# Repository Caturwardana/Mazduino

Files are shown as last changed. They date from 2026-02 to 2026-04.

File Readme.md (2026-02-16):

# Mazduino
*Mazduino ECU* is compatible with firmware from rusEFI and can also be used with Speeduino.  
For tuning and configuration, you can use the Tuner Studio software.

## Mazduino ECU Compact
Assembled Mazduino ECU
A compact and customizable Engine Control Unit (ECU) designed for **4-cylinder engines with full sequential injection and ignition**.

## Mazduino ECU Mini 6Ch
Assembled Mazduino ECU
A mini 6-channel version of the Mazduino ECU for **6-cylinder engines with full sequential injection and ignition**.

## Mazduino ECU Lite Edition
Mazduino Lite Edition
A lightweight and compact ECU designed for **4-cylinder engines with full sequential injection and wasted spark ignition**.

## Mazduino Display
Mazduino Display
A dedicated dashboard ECU display module that shows real-time vehicle data retrieved from the main ECU.

## Mazduino WBO (Wideband Oxygen Sensor Controller)
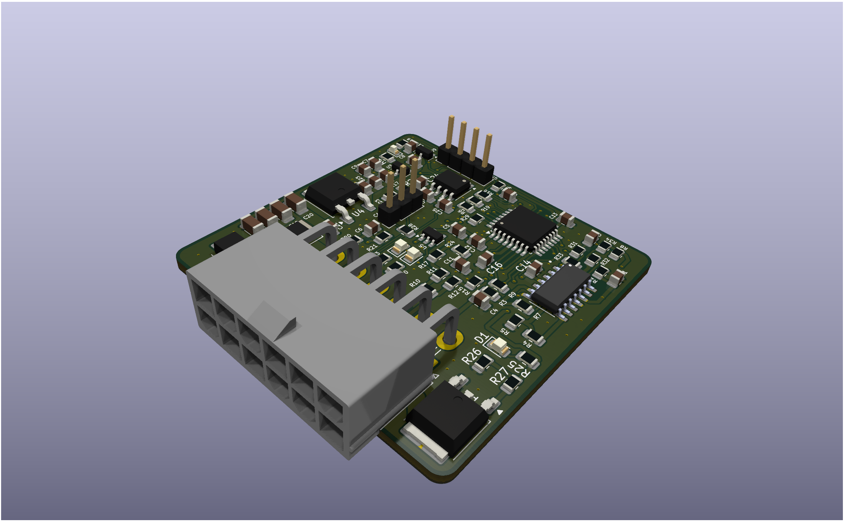
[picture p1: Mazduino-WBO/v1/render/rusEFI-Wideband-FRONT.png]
Mazduino WBO

A wideband oxygen sensor controller that communicates with the ECU via CAN bus for accurate air-fuel ratio monitoring. Supports LSU 4.2, LSU 4.9, and LSU 4.9 Adv sensors with easy manual assembly design.

*Documentation for all variants will be updated as soon as possible.*

## Links
### Mazduino
- **Official Website**: https://www.mazduino.com
- **Documentation & WIKI**: https://wiki.mazduino.com

### Firmware & Software
- **rusEFI**: https://rusefi.com/
- **Speeduino**: https://speeduino.com/home/
- **Tuner Studio**: https://www.tunerstudio.com/index.php/tuner-studio

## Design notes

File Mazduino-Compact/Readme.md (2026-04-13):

# Mazduino Compact
Assembled Mazduino ECU

Mazduino Compact is compatible with firmware from rusEFI and can also be used with Speeduino.  
For tuning and configuration, you can use the Tuner Studio software.

## Downloads

### Latest Version (v2.5)
- [Download Schematic (PDF)](https://github.com/amrikarisma/Mazduino/blob/main/Mazduino-Compact/v2.5/Schematics.pdf)
- [Interactive BOM v2.5](https://www.mazduino.com/ibom/compact-2-5-ibom.html)

### Other Versions
- [Download Schematic v2.4 (PDF)](https://github.com/amrikarisma/Mazduino/blob/main/Mazduino-Compact/v2.4/Schematics.pdf)
- [Interactive BOM v2.4](https://www.mazduino.com/ibom/compact-2-4-ibom.html)
- [Interactive BOM v2.3](https://www.mazduino.com/ibom/compact-2-3-ibom.html)
- [Interactive BOM v2.2](https://www.mazduino.com/ibom/compact-2-2-ibom.html)
- [Interactive BOM v2.0](https://www.mazduino.com/ibom/compact-2-0-ibom.html)
- [Interactive BOM v1.3](https://www.mazduino.com/ibom/compact-1-3-ibom.html)
*Interactive BOM for other versions will be available soon*

## Changelog

### v1.0
- Initial testing

### v1.1
- Fixed USB-C to USB-C connection: rerouted 5.1k resistor to CC1 & CC2  
- Corrected silkscreen typo  

### v1.2
- Added low-current output for main relay  
- Added spare analog input  
- Added jumper footprint  

### v2.0
- Replaced connector with a 33-pin Yamaha automotive connector  
- Changed 12V capacitor size from 5x5 to 6x5  

### v2.1
- Added one high-current low-side MOSFET for boost/VVT/Idle2 control  
- Added direct knock sensor support using an op-amp IC  
- Supported two types of CAN bus transceivers: MCP2551 or TJA1051T/3  
- Added a dedicated connector for CAN bus communication  
- Added a pin header footprint for VBAT, allowing real-time clock backup with a 3.3V battery

### v2.2
- Added high-side MOSFET for 12V switching control (alternator and other components requiring 12V switching)  

### v2.3
- Fixed MCU mapping for 12V battery input and knock sensor input  
- Optimized component selection and PCB layout for improved reliability and manufacturing efficiency  
- Added JST connector footprint for usb connector options  
- Added CR1220 battery holder footprint for real-time clock backup power  

### v2.4
- Optimized Hall input circuit  
- Updated pin mapping for knock input and TPS input  

### v2.5
- Optimized Hall input and analog input  
- Updated pin mapping for high-side outputs  
- HS1 moved to PD15 and HS2 moved to PD14  
- Added optional jumper for HS2 (High Side Output 2)

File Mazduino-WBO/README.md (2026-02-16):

# Mazduino WBO (Wideband Oxygen Sensor Controller)

## PCB Views

| Top View (Component Side) | Bottom View |
|:---:|:---:|
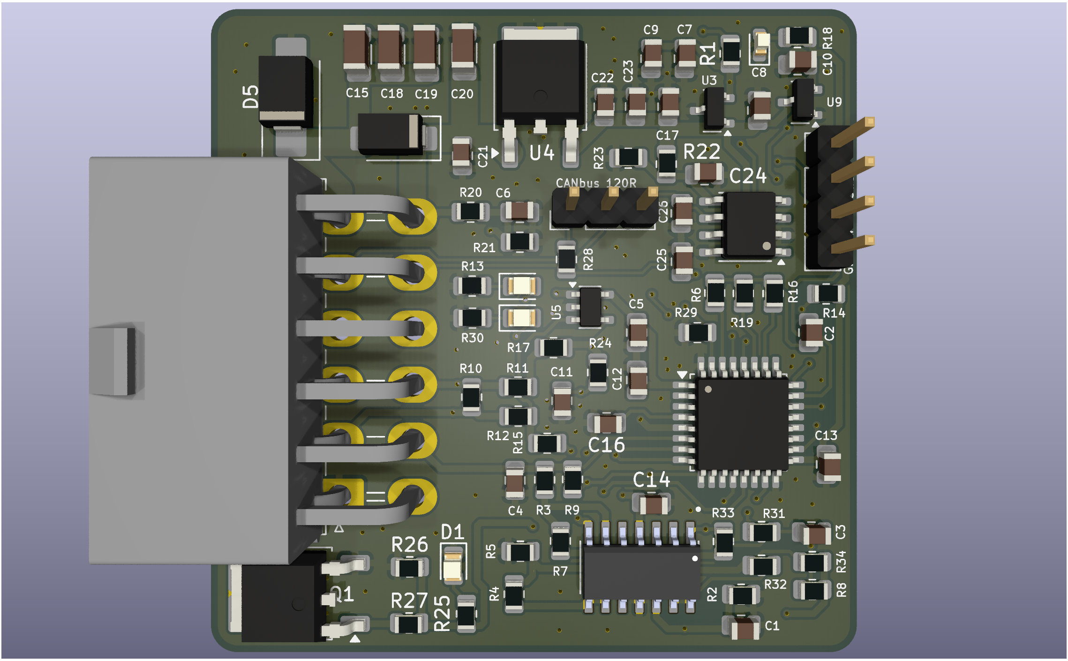
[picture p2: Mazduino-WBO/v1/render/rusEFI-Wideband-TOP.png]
Mazduino WBO Top
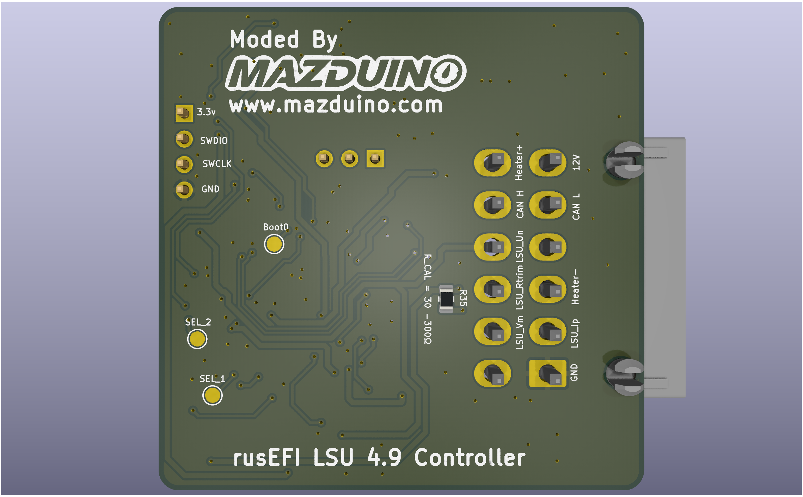
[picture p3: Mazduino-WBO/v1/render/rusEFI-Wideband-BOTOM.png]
Mazduino WBO Bottom
|  |  |

The **Mazduino WBO** is a Fork of the original Wideband Oxygen sensor controller designed to work with the rusEFI ecosystem. This project is specifically redesigned with components that are easier to manually assemble and uses economical Molex connectors to reduce cost while maintaining functionality.

## Overview

The Mazduino WBO provides accurate air-fuel ratio (AFR) monitoring for engine tuning and performance optimization. This module communicates with your ECU via **CAN bus**, enabling real-time AFR data transmission for precise fuel management. It's designed to be a cost-effective solution for DIY engine management enthusiasts who want reliable wideband oxygen sensor control.

## Key Features

- **CAN Bus Communication**: Communicates with ECU via CAN bus for real-time AFR data transmission
- **Multiple LSU Sensor Support**: Compatible with LSU 4.2, LSU 4.9, and LSU 4.9 Adv sensors
- **Easy Manual Assembly**: Redesigned with components that are straightforward to solder and assemble by hand
- **Economical Connectors**: Uses cost-effective Molex connectors instead of expensive alternatives
- **rusEFI Compatible**: Fully compatible with the rusEFI ecosystem for seamless integration
- **Open Source**: Complete schematics, PCB design files, and firmware available
- **Proven Design**: Based on the reliable [mck1117/wideband](https://github.com/mck1117/wideband) controller

## Hardware Versions

### v1.0
- Initial release with improved component selection for manual assembly
- Cost-optimized Molex connector implementation
- Supports LSU 4.2, LSU 4.9, and LSU 4.9 Adv sensors (tested and verified with LSU 4.9)
- Complete gerber files and assembly documentation included
- **Interactive BOM**: [View Interactive Bill of Materials](https://www.mazduino.com/ibom/wideband-controller-v1-ibom.html)

## Firmware

This project uses the **rusEFI WBO F0** firmware, which provides:
- Accurate AFR readings
- CAN bus communication
- Calibration and diagnostic features

**Firmware Source**: [rusEFI WBO F0 Implementation](https://github.com/rusefi/rusefi/pull/8870)

## Getting Started

### Hardware Requirements
- Mazduino WBO PCB (v1.0 or later)
- **Wideband oxygen sensor**: Supports LSU 4.2, LSU 4.9, and LSU 4.9 Adv (tested with LSU 4.9)
- 12V power supply
- **CAN bus connection** to ECU (primary communication method)

### Connector Pinout

The Mazduino WBO uses a **Molex 2x6 connector** for easy assembly and cost-effective connections.

Mazduino WBO Front

#### Pinout Layout:

<table>
<tr>
<td>Heater+</td>
<td>CANH</td>
<td>LSU_Un</td>
<td>LSU_Rtrim</td>
<td>LSU_Vm</td>
<td>Empty</td>
</tr>
<tr>
<td>+12V</td>
<td>CANL</td>
<td>Empty</td>
<td>Heater-</td>
<td>LSU_Ip</td>
<td>GND</td>
</tr>
</table>

*Row 1 (Top) and Row 2 (Bottom) of the Molex 2x6 connector*

#### LSU 4.9 Wire Colors:
| Signal | Wire Color | Pin Location |
|:---|:---|:---|
| LSU_Ip | Red | Row 2, Pin 5 |
| Heater- | White | Row 2, Pin 4 |
| Heater+ | Grey | Row 1, Pin 1 |
| LSU_Vm | Yellow | Row 1, Pin 5 |
| LSU_Rtrim  | Green | Row 1, Pin 4 |
| LSU_Un | Black | Row 1, Pin 3 |

### Assembly
1. Follow the assembly guide in the `v1/` directory
2. Refer to the BOM (Bill of Materials) for required components
3. Use the **[Interactive BOM](https://www.mazduino.com/ibom/wideband-controller-v1-ibom.html)** for easy component identification and placement
4. Use the provided schematics for proper component placement

### Firmware Installation
1. Download the rusEFI WBO F0 firmware from the official repository
2. Flash the firmware using your preferred STM32 programming tool
3. Configure the controller according to your sensor specifications

## Project Structure

```
Mazduino-WBO/
├── README.md           # This file
└── v1/                 # Version 1.0 files
    ├── Readme.md       # Version-specific documentation
    ├── Schematics.pdf  # Circuit schematics
    └── gerber/         # PCB manufacturing files
        ├── bom.csv             # Bill of materials
        ├── designators.csv     # Component designators
        ├── netlist.ipc         # Net list file
        ├── positions.csv       # Component positions
        └── rusEFI-WBO.zip     # Complete gerber package
```

## Attribution

This project is a fork of the excellent work by [mck1117](https://github.com/mck1117) on the original [wideband controller](https://github.com/mck1117/wideband). The Mazduino variant focuses on improving manufacturability and reducing cost while maintaining the proven functionality of the original design.

## Related Projects

- **Original Wideband Controller**: https://github.com/mck1117/wideband
- **rusEFI Project**: https://github.com/rusefi/rusefi
- **Mazduino ECU Family**: See main project directory for other Mazduino variants

## Contributing

Contributions are welcome! Please feel free to submit issues, feature requests, or pull requests to improve the Mazduino WBO design.

## License

This project follows the same license terms as the original wideband controller project.

## Support & Documentation

- **Official Website**: https://www.mazduino.com
- **Documentation & WIKI**: https://wiki.mazduino.com
- **rusEFI Community**: https://rusefi.com/forum/

---

*For questions or support, please visit the Mazduino community forums or create an issue in this repository.*

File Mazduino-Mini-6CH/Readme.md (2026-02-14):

# Mazduino Mini 6Ch

Mazduino Mini 6Ch is compatible with firmware from rusEFI and can also be used with Speeduino.  
For tuning and configuration, you can use the Tuner Studio software.

## Preview
<table>
  <tr>
    <td>3D Render top</td>
    <td>3D Render bottom</td>
  </tr>
  <tr>
    <td>3D Render side</td>
    <td>Assembled Mazduino ECU</td>
  </tr>
</table>

## Features
- Processor/MCU: STM32F407
- 6 Channel Coil outputs for Smart Coil (For dumb coil, please add external IGBT)
- 6 Channel Injector outputs
- 2 High Current Outputs (Idle/Boost/VVT)
- Tachometer Output
- Fuel Pump Low Current Output
- FAN Low Current Output
- AC Compressor Low Current Output
- CKP Trigger Input (Hall/Optical/VR)
- CMP Trigger Input (Hall/Optical/VR)
- Supports VR-Conditioner Module (DIP 8)
- Supports Stepper Module (DRV8825)
- External MAP Sensor Analog Input
- TPS Sensor Analog Input
- IAT Sensor Analog Input
- ECT/CLT Sensor Analog Input
- O2 Sensor Analog Input
- Spare Analog Input 1 (Can be used for Fuel Pressure Sensor or others)
- Spare Analog Input 2 (Can be used for Oil Pressure Sensor or others)
- AC Switch Digital Input/GND signal
- Launch Control Input
- Clutch Input
- VSS Input
- Supports Micro SD Card for data logging via SPI
- Supports CANbus communication with MCP2551 IC
- Automotive 48-pin Yamaha ECU Connector

## Downloads

### Latest Version (v1.4)
- [Download Schematic (PDF)](https://github.com/amrikarisma/Mazduino/blob/main/Mazduino-Mini-6CH/v1.4/Schematics.pdf)
- [Interactive BOM v1.4](https://www.mazduino.com/ibom/mini6ch-1-4-ibom.html)

### Other Versions
- [Interactive BOM v1.3](https://www.mazduino.com/ibom/mini6ch-1-3-ibom.html)
- [Interactive BOM v1.3B](https://www.mazduino.com/ibom/mini6ch-1-3b-ibom.html)
- [Interactive BOM v1.2](https://www.mazduino.com/ibom/mini6ch-1-2-ibom.html)
  
## Changelog

### v1.0
- Initial Release

### v1.1
- Fix USB D+ and D-
- Add 2 Spare analog inputs
- Change AC Switch from Analog Input to Digital Pin (GND signal)

### v1.2
- Replace footprint Capacitor for Input Regulator 5V from 5x5 to 8x6
- Add low current output for Main relay control
- Fix DRV8825 schema for rusEFI

### v1.3
- Added ETB support
- Added Knock sensor support

### v1.3B
- Added 1 spare input to support ETB. For ETB to work, it needs TPS1, TPS2, PPS1, PPS2. Previously PPS2 shared with O2/IAT input (unused analog input)
- CAN IC only supports TJA1051T/J/3 (Solder jumper for MCP2551 removed)
- Footprint optimization
- DRV8825 module support is still maintained

### v1.4 (latest)
- Added spare inputs to support TPS1, TPS2, PPS1, PPS2
- Added support for ETB1 and ETB2
- Motor driver uses 2x TLE9201SG ICs (can be used for Idle Stepper Motor when not used for ETB)
- Removed DRV8825 module support

---

*This documentation will be updated as soon as possible... please wait.*

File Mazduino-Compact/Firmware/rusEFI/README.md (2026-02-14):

# rusEFI Firmware for Mazduino-Compact

## Overview
This directory contains rusEFI firmware and configuration files for the Mazduino-Compact ECU board.

## Firmware Download Options

### Important Note
You are **not required** to use the `rusefi.hex` file that may be present in this folder. You can download the latest firmware directly from the official rusEFI build server.

### Official Download Links

#### Discovery F407 Platform
- **Download URL:** https://rusefi.com/build_server/rusefi_bundle_f407-discovery.zip
- **Platform:** Discovery F407
- **Description:** Latest stable firmware build for STM32F407-based boards

#### Mega100 Platform  
- **Download URL:** https://rusefi.com/build_server/rusefi_bundle_mega100.zip
- **Platform:** Mega100
- **Description:** Latest stable firmware build for Mega100 platform

## Installation Instructions

1. Download the appropriate firmware bundle from one of the links above
2. Extract the downloaded zip file
3. Use the rusEFI Console or your preferred flashing tool to upload the firmware
4. Apply the base tune configuration from the `basetune/` folder if available

## Configuration Files

Check the `basetune/` directory for:
- Base tune files (.msq)
- Configuration templates
- Sensor calibration data

## Support and Documentation

- **Official Website:** https://rusefi.com/
- **Documentation:** https://wiki.rusefi.com/
- **Community Forum:** https://rusefi.com/forum/
- **GitHub Repository:** https://github.com/rusefi/rusefi

## Compatibility

This firmware is designed for use with the Mazduino-Compact ECU board. Ensure you select the correct platform variant when downloading from the build server.

## Updates

Always check the official rusEFI build server for the latest firmware versions, as they include the newest features, bug fixes, and improvements.

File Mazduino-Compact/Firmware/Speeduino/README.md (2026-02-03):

# Speeduino Firmware for Mazduino-Compact

## Important Notice

### Custom Firmware Required
The Mazduino ECU can **ONLY** run **custom Speeduino firmware**. The official Speeduino firmware from the main project **will NOT work** with Mazduino boards due to hardware differences and pin mapping requirements.

### Compatibility Warning
- ⚠️ **DO NOT** use official Speeduino firmware releases
- ⚠️ **DO NOT** download firmware from speeduino.com for direct use
- ✅ **ONLY** use the custom firmware provided in this repository

## Board Compatibility

### Tested Hardware
- **Mazduino Compact v1.x** - ✅ Fully tested and supported

### Untested/Unsupported
- **Mazduino Compact v2.x and above** - ⚠️ Not tested with this firmware
- **Other Mazduino variants** - ⚠️ May require different firmware versions

## Firmware Versions Available

Check the version folders for available firmware builds:
- `202501/` - January 2025 custom build
- `202501.2/` - January 2025 revised build
- `basetune/` - Base configuration files

## Installation Instructions

1. **Select the appropriate version** from the available folders
2. **Use Arduino IDE or PlatformIO** to flash the custom firmware
3. **Apply base tune settings** from the `basetune/` folder
4. **Verify pin mapping** matches your specific Mazduino Compact v1 board

## Why Custom Firmware?

The Mazduino boards use different:
- Pin assignments compared to standard Arduino Mega
- Hardware layout and connections
- Sensor input configurations
- Output driver arrangements

These differences require custom firmware modifications that are not present in the official Speeduino releases.

## Support and Resources

- **Mazduino Documentation:** Check the main repository wiki
- **Speeduino Community:** https://speeduino.com/forum/ (for general Speeduino questions)
- **Custom Firmware Issues:** Report in the Mazduino project repository

## Upgrading Board Versions

If you have a **Mazduino Compact v2.x or newer**, check the appropriate firmware directory for your board version, as this firmware is specifically for v1.x boards only.

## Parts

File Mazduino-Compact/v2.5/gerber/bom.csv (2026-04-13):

Designator | Footprint | Quantity | Value | LCSC Part #
BT1 | CR1220-2 | 1 | Battery_Cell
C1, C15, C66, C67 | 0603 | 4 | 1nF | C1588
C12, C16, C19, C20, C3, C35, C38, C39, C4, C40, C41, C5, C6, C7, C8, C9 | 0603 | 16 | 100nF | C14663
C17 | CP_Elec_6.3x5.4 | 1 | 10uF
C18, C2, C24, C30, C36, C42, C43, C44, C45, C46, C54, C56 | 0603 | 12 | 100nF
C21 | CP_Elec_5x5.3 | 1 | 47uF
C22, C55 | 0603 | 2 | 1uF | C15849
C23, C26 | 0603 | 2 | 33pF | C1663
C25, C29, C31, C33, C57 | 0603 | 5 | 1uF
C27 | 0603 | 1 | 20pF | C1648
C28 | 0603 | 1 | 20pF
C32 | 0603 | 1 | 2.2uF | C23630
C34 | 0603 | 1 | 2.2uF
C37 | CP_Elec_5x5.4 | 1 | 47uF
C49 | 0603 | 1 | 3.3nF
C50 | 0603 | 1 | 680pF
C51 | 0603 | 1 | 330pF
C52 | 0603 | 1 | 47pF
C53 | 0603 | 1 | 10nF
C58, C59 | 0603 | 2 | 10nF | C57112
D1, D2, D3, D4, D7, D8, D9 | 0603 | 7 | LED
D10 | 0603 | 1 | LED | C2290
D11 | D_SOD-323_HandSoldering | 1 | 1N4148WS | C2128
D12, D6 | D_SOD-323_HandSoldering | 2 | 1N4148WS
D13, D16, D25, D26, D29, D31, D32, D33 | D_SOD-123 | 8 | 1N5819W
D14 | D_SMA | 1 | SS14 | C2480
D15 | D_SMA | 1 | SMBJ20A
D17 | SOT-23 | 1 | BAT54S | C7420333
D18, D19, D20, D21, D22, D23, D24, D27, D30, D35 | SOT-23 | 10 | BAT54S
D34 | SOT-23 | 1 | BAT54C
D5 | D_SOD-323_HandSoldering | 1 | 1N4148WS | C2286
F1, F2 | 1206 | 2 | Fuse 500mA
IC3 | SOT95P280X145-6N | 1 | SN74LVC2G17DBVR | C10429
J1 | JST_XH_S4B-XH-A-1_1x04_P2.50mm_Horizontal | 1 | Conn_01x04
J10 | JST_GH_SM04B-GHS-TB_1x04-1MP_P1.25mm_Horizontal | 1 | Conn_01x04
J2 | PinHeader_1x04_P2.54mm_Vertical | 1 | STLink
J3 | USB_C_Receptacle_GCT_USB4105-xx-A_16P_TopMnt_Horizontal | 1 | TYPE-C 16PIN 2MD(073) | C2765186
J4 | PinHeader_1x01_P2.54mm_Vertical | 1 | Conn_01x01
J5 | CUI_MSD-1-A | 1 | THD2528-11SD-GF
J6, J7, J8 | PinHeader_1x02_P2.54mm_Vertical | 3 | Conn_01x02
J9 | 15544582 | 1 | 1554458-2
JP1 | SolderJumper-3_P1.3mm_Open_RoundedPad1.0x1.5mm | 1 | Ignition Voltage
JP7 | SolderJumper-3_P1.3mm_Open_RoundedPad1.0x1.5mm | 1 | PP Supply
JP8 | SolderJumper-3_P1.3mm_Open_RoundedPad1.0x1.5mm | 1 | GND/HS2
LED1, LED3, LED4 | 0603 | 3 | RED | C2286
LED2 | 0603 | 1 | RED | SML-310LTT86
Q1, Q11, Q2, Q3, Q4, Q6 | TO-252-3_TabPin2 | 6 | Q_NMOS_GDS
Q10, Q7, Q8, Q9 | SOT-23 | 4 | AO3400A | C344010
Q5 | SOT-23 | 1 | AO3400A | C20917
R1, R102, R103, R16, R18, R19, R2, R20, R3, R4, R43, R47, R5, R6 | 0603 | 14 | 1k
R10 | 0603 | 1 | 2.4k | C22940
R100, R101, R99 | 0603 | 3 | 33K
R104, R17, R58 | 0603 | 3 | 1k | C21190
R105, R106, R107 | 0603 | 3 | 470k | C23178
R108, R27, R64, R68, R69, R70, R75, R76, R77, R78, R84, R85 | 0603 | 12 | 10K
R109 | 0603 | 1 | 82K
R11, R12, R25, R26 | 0603 | 4 | 470r
R13, R65, R66, R71, R72, R73, R74 | 0603 | 7 | 5.6k
R14 | 0603 | 1 | 10k | C140066
R15 | 0603 | 1 | 1k | C25803
R21, R30, R31, R34, R38, R39, R40, R48, R59, R62, R63, R67, R8, R90, R92, R94 | 0603 | 16 | 10k | C25804
R22, R32 | 0805 | 2 | 100R | C17408
R23, R24, R9 | 0603 | 3 | 2.4k
R28, R44 | 0603 | 2 | 5.6k | C23189
R29, R33, R35, R36, R91 | 0603 | 5 | 2.7k | C13167
R37, R41, R42, R50, R51, R56, R86 | 0603 | 7 | 2k7 | C13167
R45 | 0603 | 1 | 10k | C21190
R46, R60, R61, R89, R93 | 0603 | 5 | 100R | C22775
R49 | 0603 | 1 | 1k | C13167
R52, R53, R54, R55 | 2512 | 4 | 15R 2Watt
R57 | 0603 | 1 | 470R | C13167
R7, R87, R88 | 0603 | 3 | 470r | RK73H2ATTD4700F
R79 | 0603 | 1 | 5.1K | C23186
R80 | 0603 | 1 | 5.1K
R81 | 0603 | 1 | 22R | C23345
R82 | 0603 | 1 | 22R
R83 | 0603 | 1 | 4.7K | C23162
R95, R98 | 0603 | 2 | 100K
R96 | 0603 | 1 | 470K
R97 | 0603 | 1 | 12K
SW1, SW2 | SW_SPST_CK_RS282G05A3 | 2 | SW_Push | C354943
U1 | LQFP-100_14x14mm_P0.5mm | 1 | STM32F407VGTx | C12345
U10 | SOIC127P600X175-8N | 1 | MCP6002-xSN
U11 | SOT-23-6 | 1 | SRV05-4
U2, U4, U9 | SOIC127P599X175-8N | 3 | TC4424AVOA | C44150
U3 | SOT-223-3_TabPin2 | 1 | AMS1117-3.3 | C6186
U5, U6 | SOIC127P600X175-14N | 2 | MCP6004
U7 | SOIC-8_3.9x4.9mm_P1.27mm | 1 | TJA1051T/3/1J
U8 | TO-263-3_TabPin2 | 1 | LM2940S-5.0
Y1 | Crystal_SMD_5032-2Pin_5.0x3.2mm | 1 | 8Mhz | C115962
Y2 | Crystal_SMD_3215-2Pin_3.2x1.5mm | 1 | 32.768KHz | C32346

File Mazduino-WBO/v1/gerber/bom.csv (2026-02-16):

Designator | Footprint | Quantity | Value | LCSC Part #
C1, C17, C21, C22, C24, C4, C6, C7 | 0805 | 8 | 1u | C28323
C10 | 0805 | 1 | 4.7u | C1779
C11, C12, C13, C14, C16, C2, C5, C8, C9 | 0805 | 9 | 100n | C28233
C15, C18, C19, C20 | 1206 | 4 | 10u | C13585
C23 | 0805 | 1 | 22u | C45783
C25, C26 | 0805 | 2 | 47p | C14857
C3 | 0805 | 1 | 33n | C1739
D1 | 0805 | 1 | RED | C2286
D2 | 0805 | 1 | GREEN | C84256
D3 | 0805 | 1 | BLUE | C84256
D4 | 0603 | 1 | RED | C2286
D5 | D_SMB_Handsoldering | 1 | D_TVS | C151279
D6 | D_SMA | 1 | SS14 | C2480
J1 | Molex_Mini-Fit_Jr_5569-12A2_2x06_P4.20mm_Horizontal | 1 | Conn_02x06_Top_Bottom
J2 | PinHeader_1x04_P2.54mm_Vertical | 1 | Conn_01x04_Pin
J3, J5, J6 | TestPoint_Pad_D1.5mm | 3 | Conn_01x01_Pin
J4 | PinHeader_1x03_P2.54mm_Vertical | 1 | CAN_Terminator
Q1 | TO-252-2 | 1 | BTS3028 | C112639
R1, R13, R18, R2, R25, R26, R27, R30 | 0805 | 8 | 1k | C17513
R10 | 0805 | 1 | 61.9 | C17779
R11, R12, R21, R29, R3, R33, R34, R4 | 0805 | 8 | 10k | C17414
R14 | 0805 | 1 | 62k | C17783
R15, R17, R20 | 0805 | 3 | 100k | C149504
R16 | 0805 | 1 | 6.8k | C17772
R19 | 0805 | 1 | 47k | C17713
R22 | 0805 | 1 | 220 | C17557
R23 | 0805 | 1 | 470 | C17710
R24 | 0805 | 1 | 3.3k | C26010
R28 | 0805 | 1 | 120R | C17437
R31, R32 | 0805 | 2 | 68k | C17801
R35 | 0805 | 1 | DNP
R5, R7 | 0805 | 2 | 27k | C17593
R6 | 0805 | 1 | 22k | C17560
R8 | 0805 | 1 | 47 | C17714
R9 | 0805 | 1 | 10 | C17415
U1 | SOIC127P600X175-14N | 1 | MCP6004 | C7378
U2 | LQFP-32_7x7mm_P0.8mm | 1 | STM32F042K6Tx | C69216
U3 | SOT-23 | 1 | REF3033 | C36658
U4 | TO-252-2 | 1 | LM78M05_TO252 | C58069
U5 | TSOT-23-5 | 1 | AD8628 | C29309
U6 | SOIC-8_3.9x4.9mm_P1.27mm | 1 | TJA1051T-3 | C38695
U9 | SOT-23 | 1 | XC6206P332MR | C5446

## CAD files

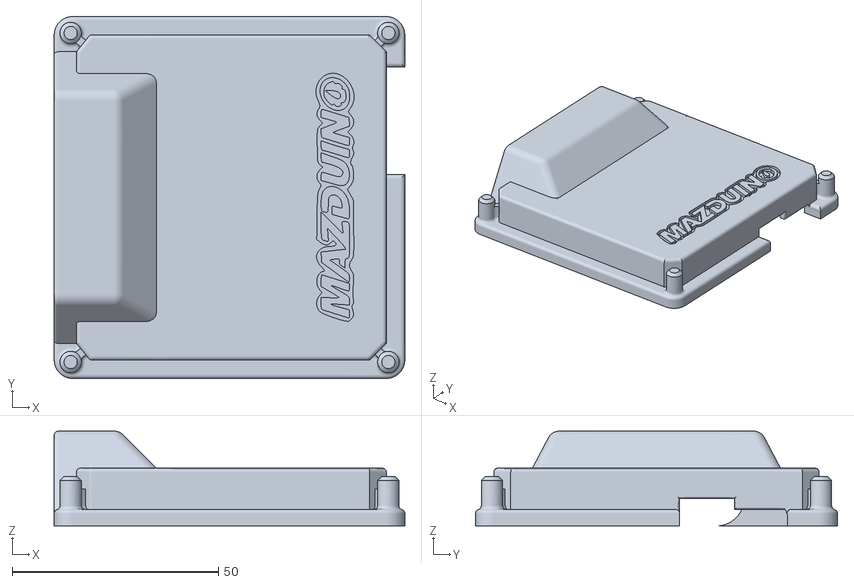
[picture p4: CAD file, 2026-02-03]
Mazduino-Lite/3D Case/LITE_TOP.stl.stl
85.1 x 87.9 x 23.0

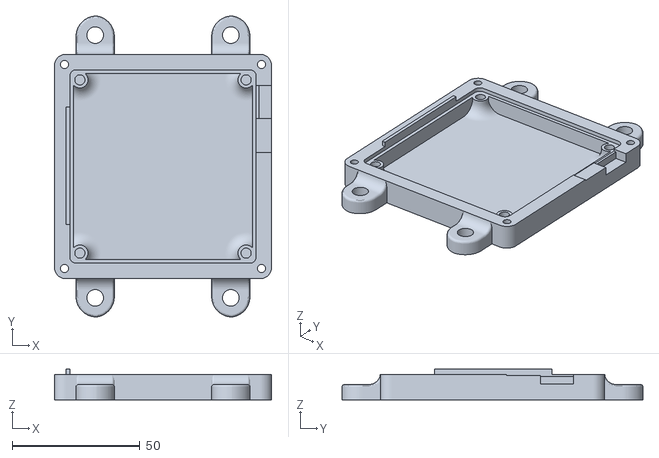
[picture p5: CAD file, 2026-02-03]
Mazduino-Lite/3D Case/LITE_BOTTOM.stl.stl
85.1 x 117.8 x 12.0

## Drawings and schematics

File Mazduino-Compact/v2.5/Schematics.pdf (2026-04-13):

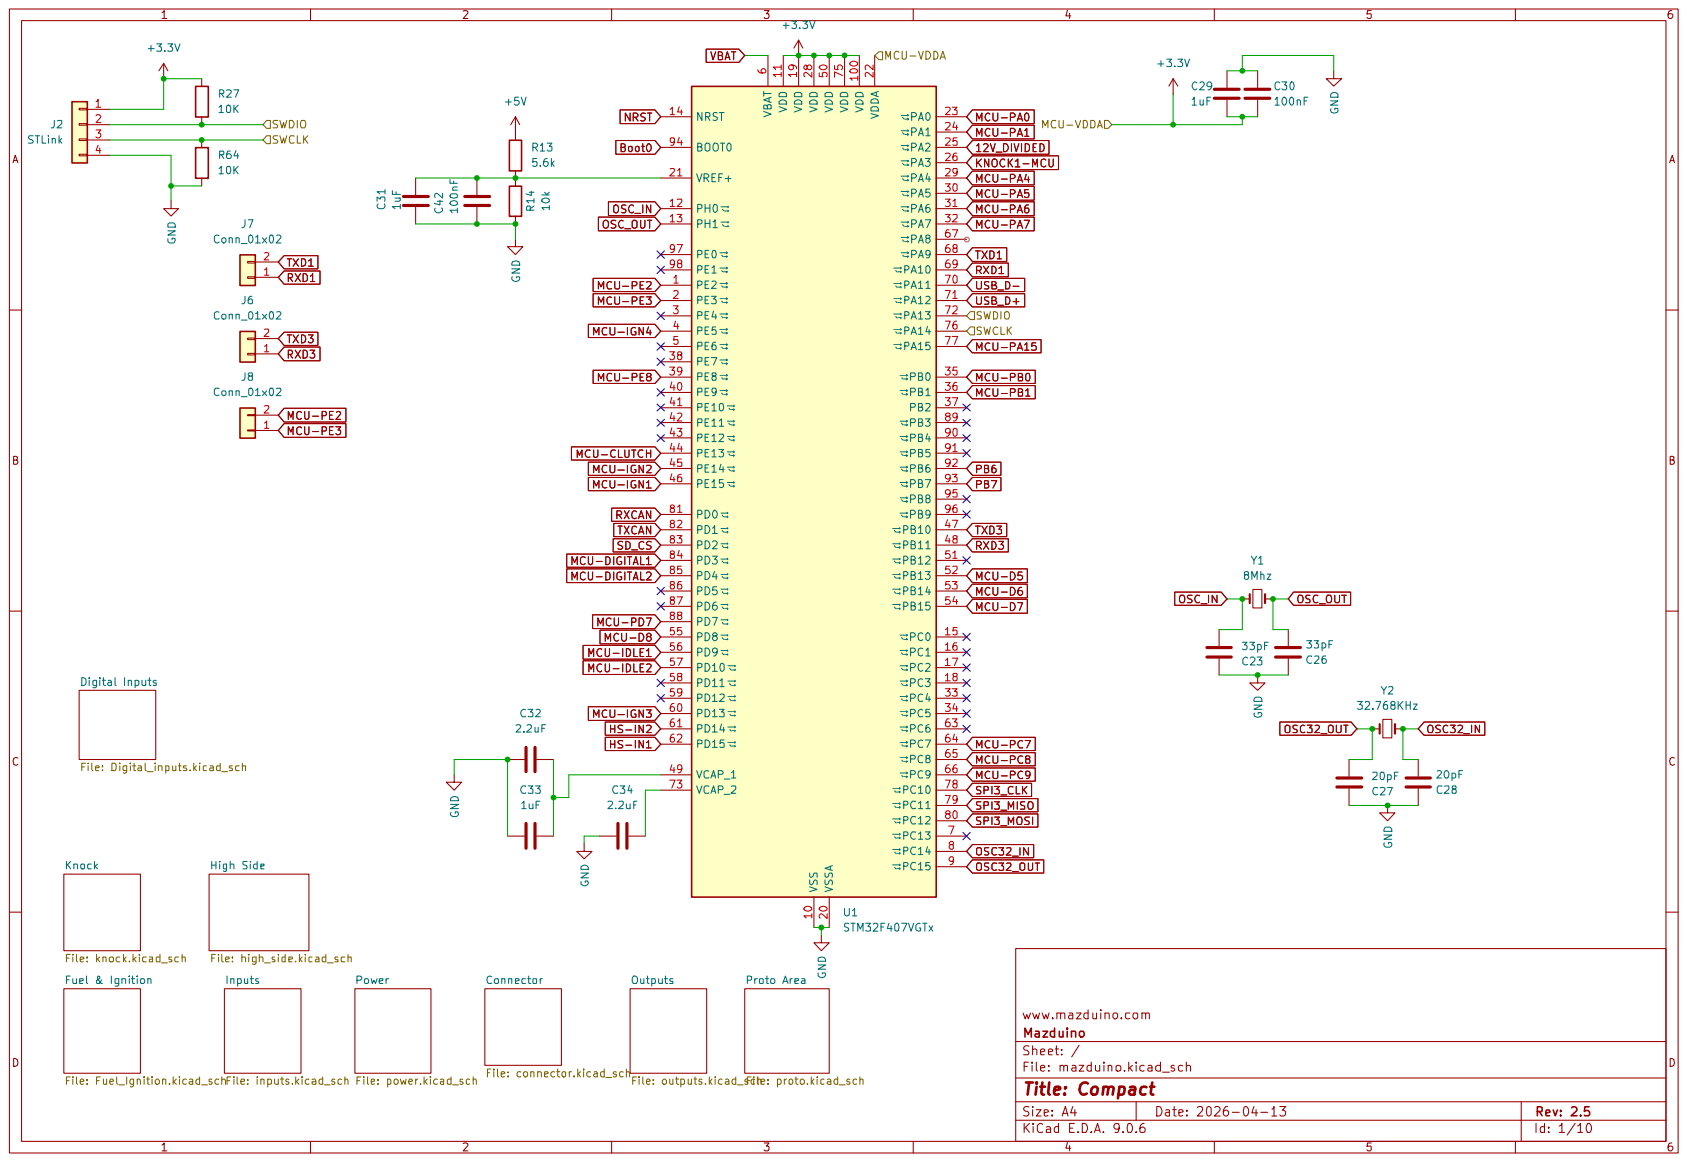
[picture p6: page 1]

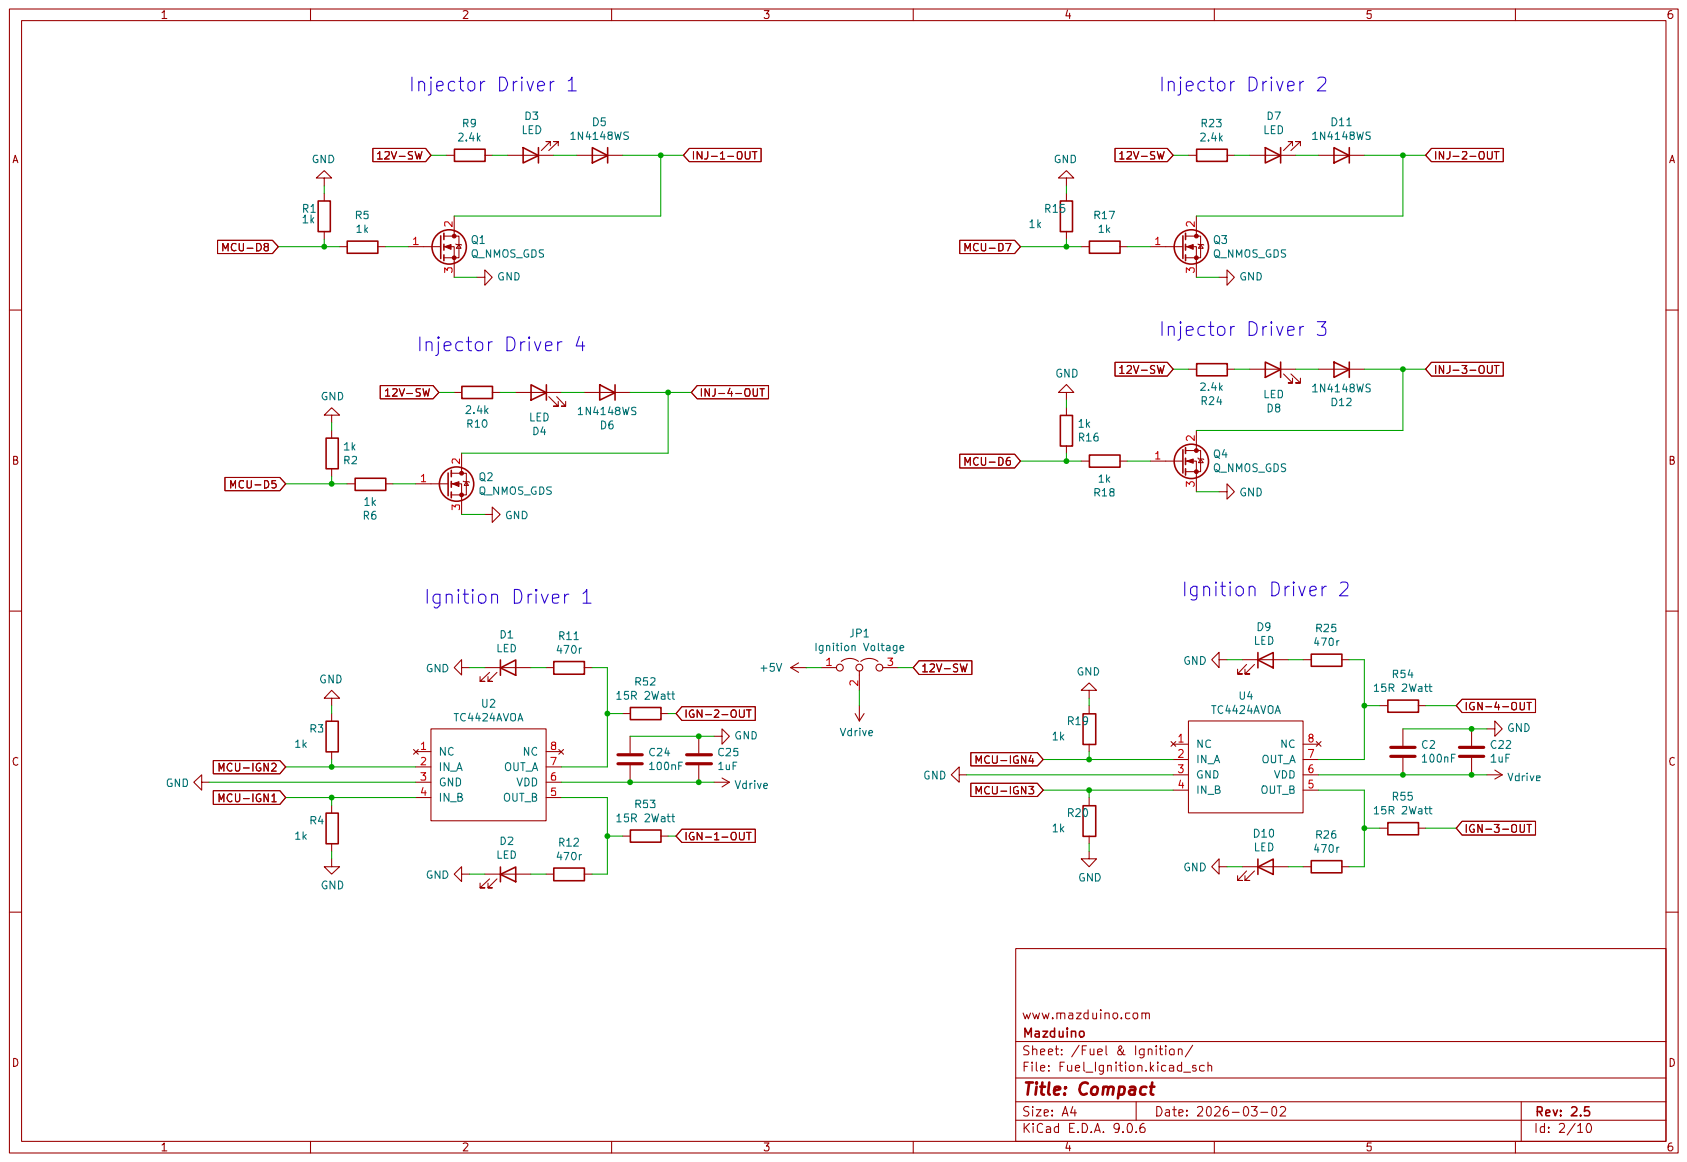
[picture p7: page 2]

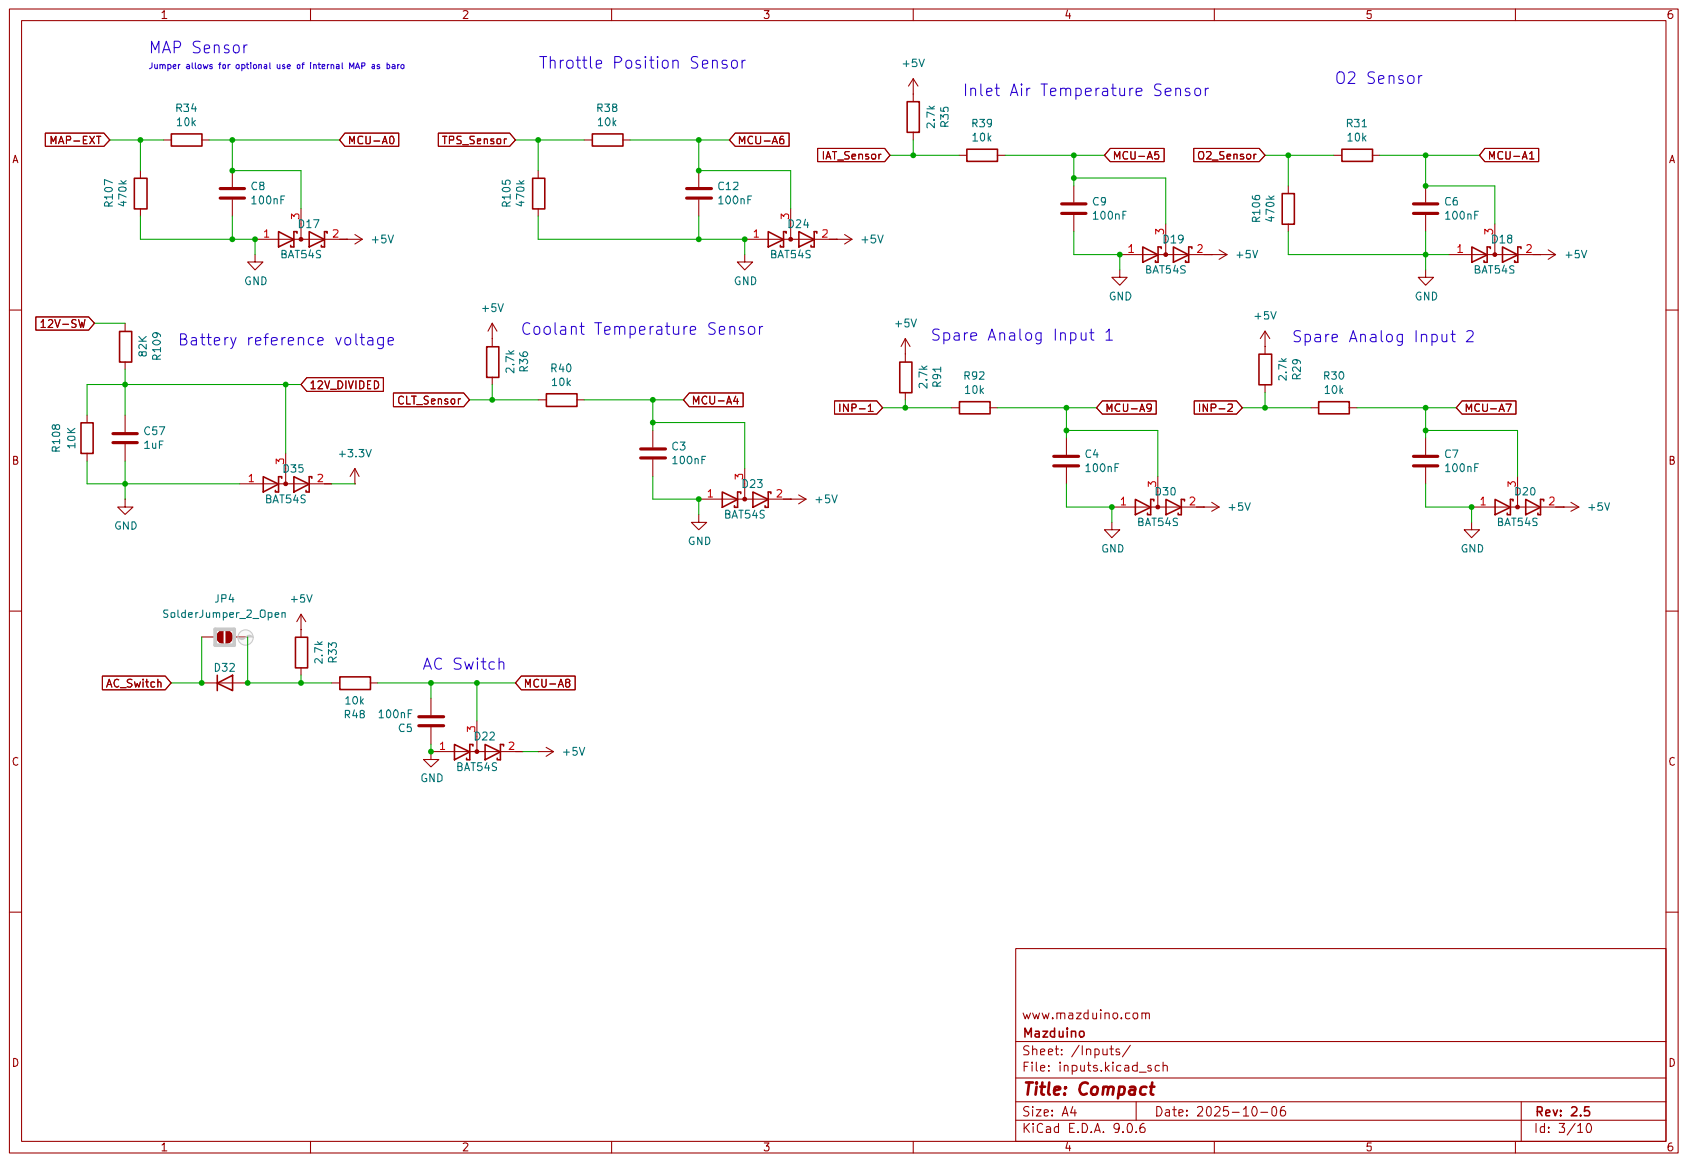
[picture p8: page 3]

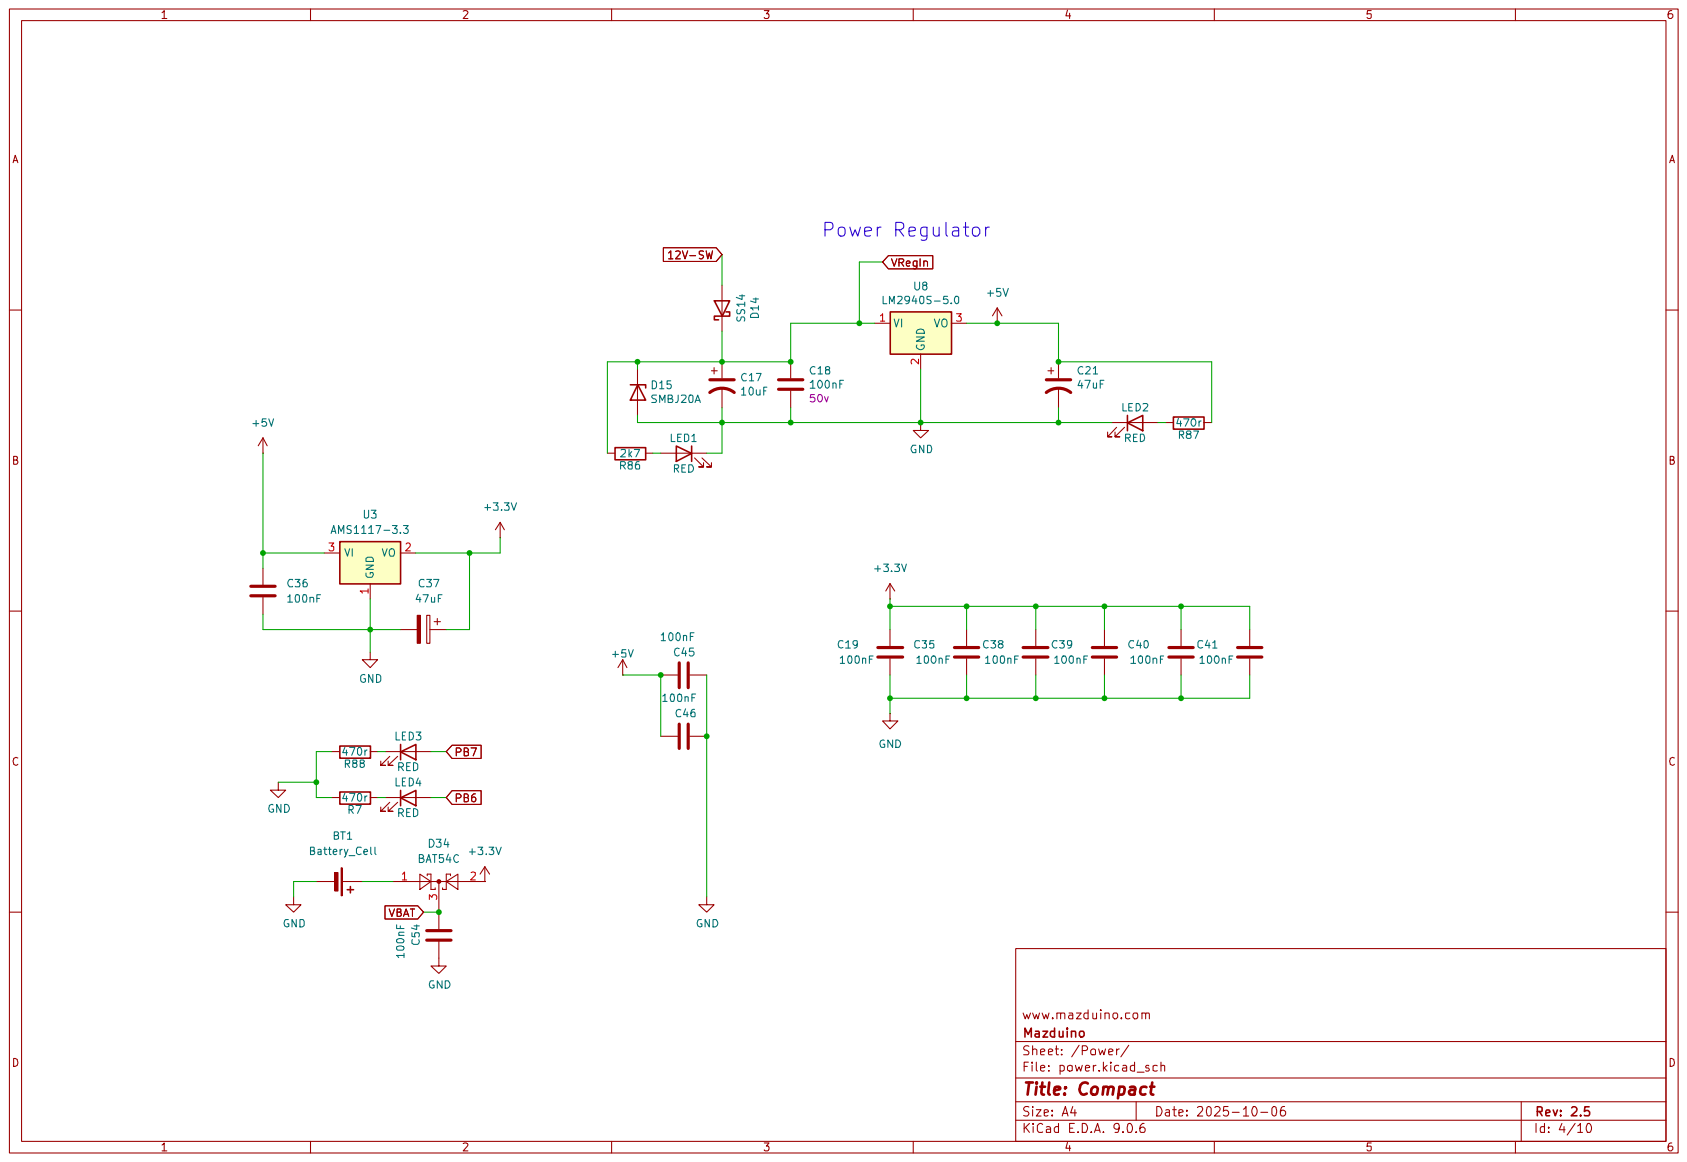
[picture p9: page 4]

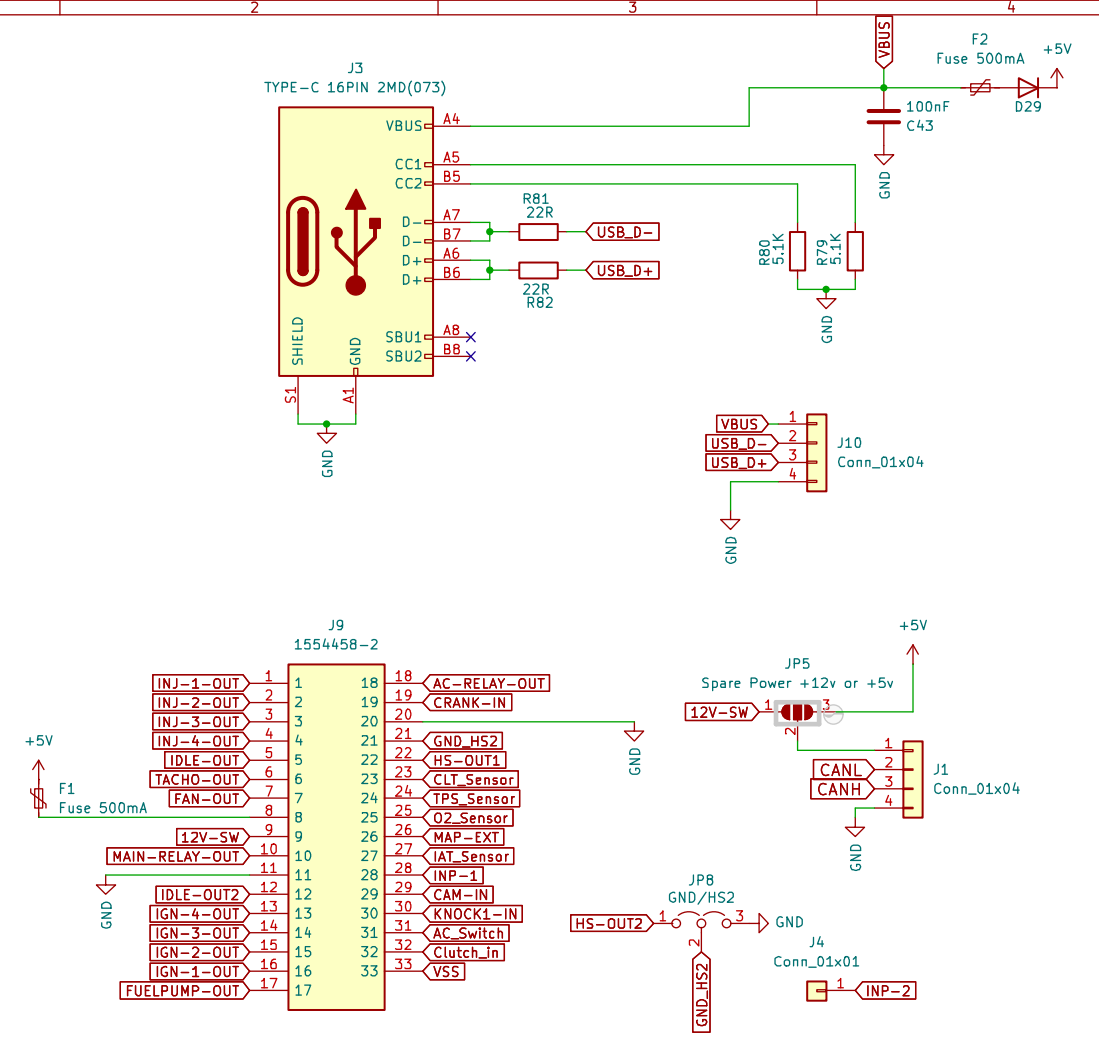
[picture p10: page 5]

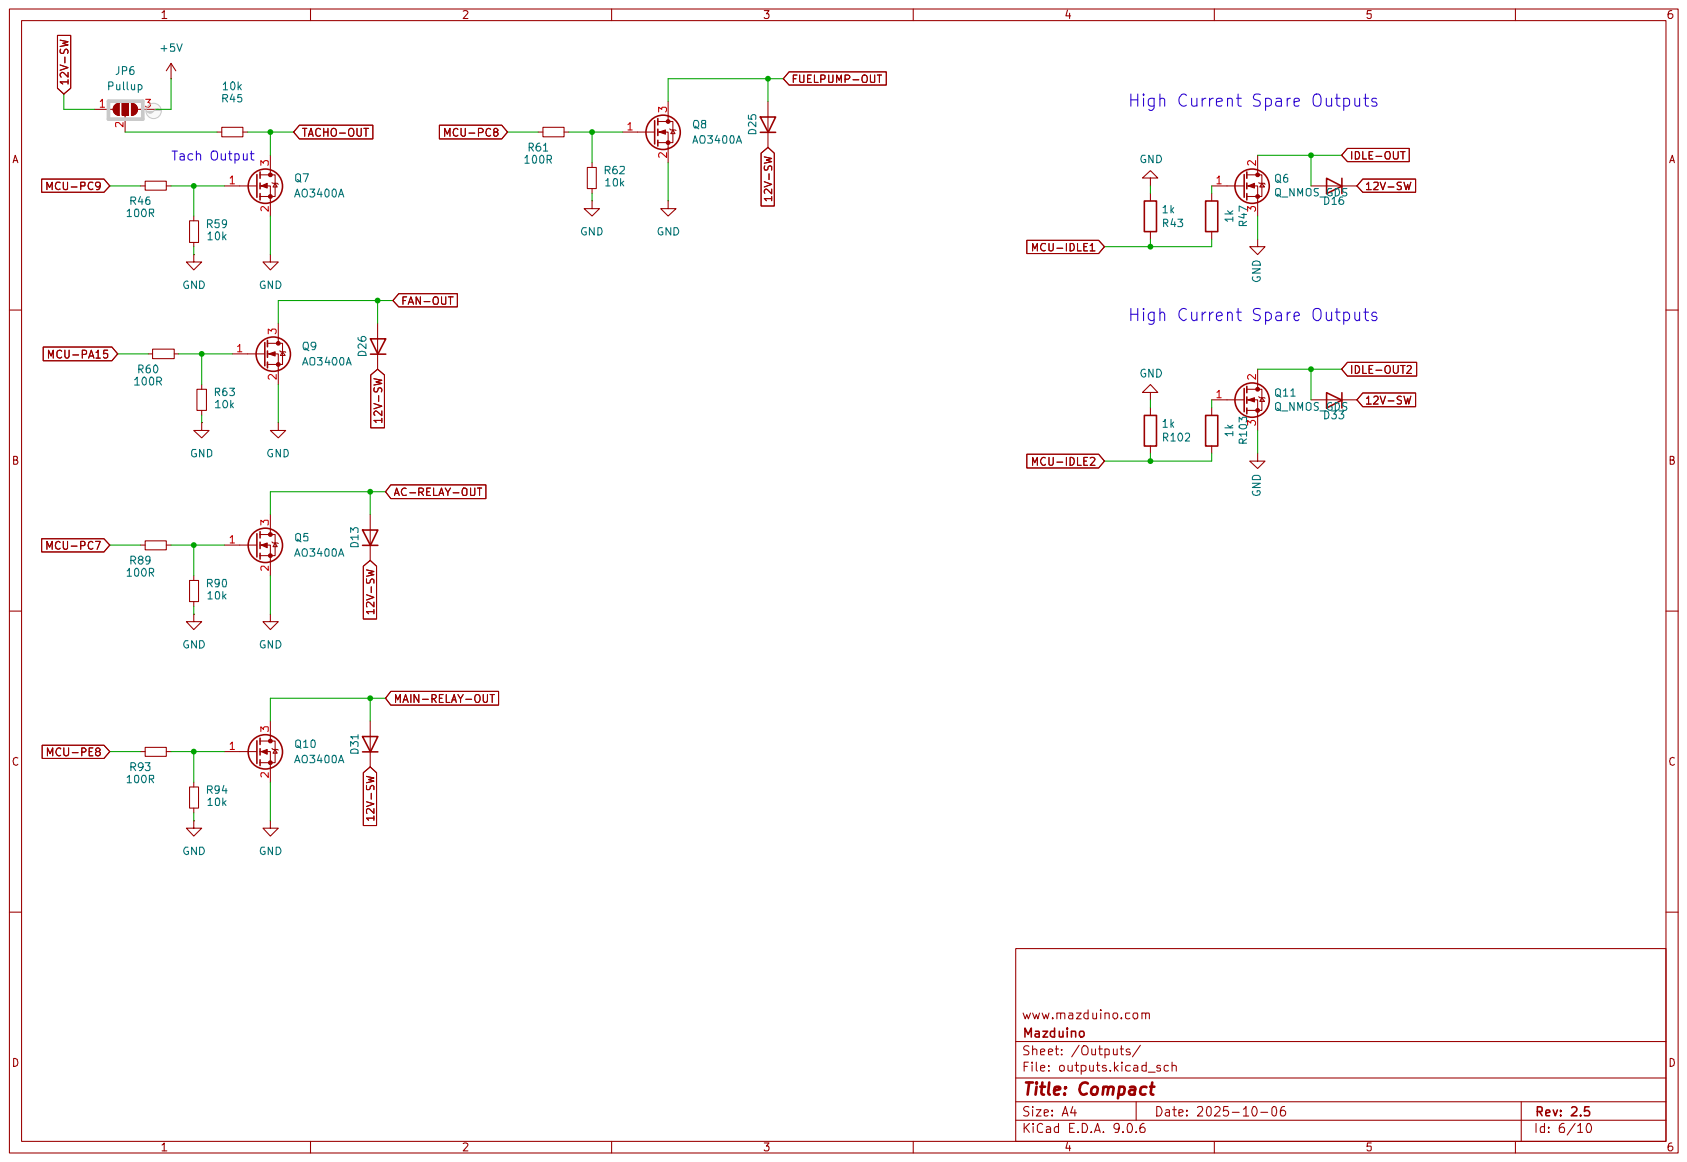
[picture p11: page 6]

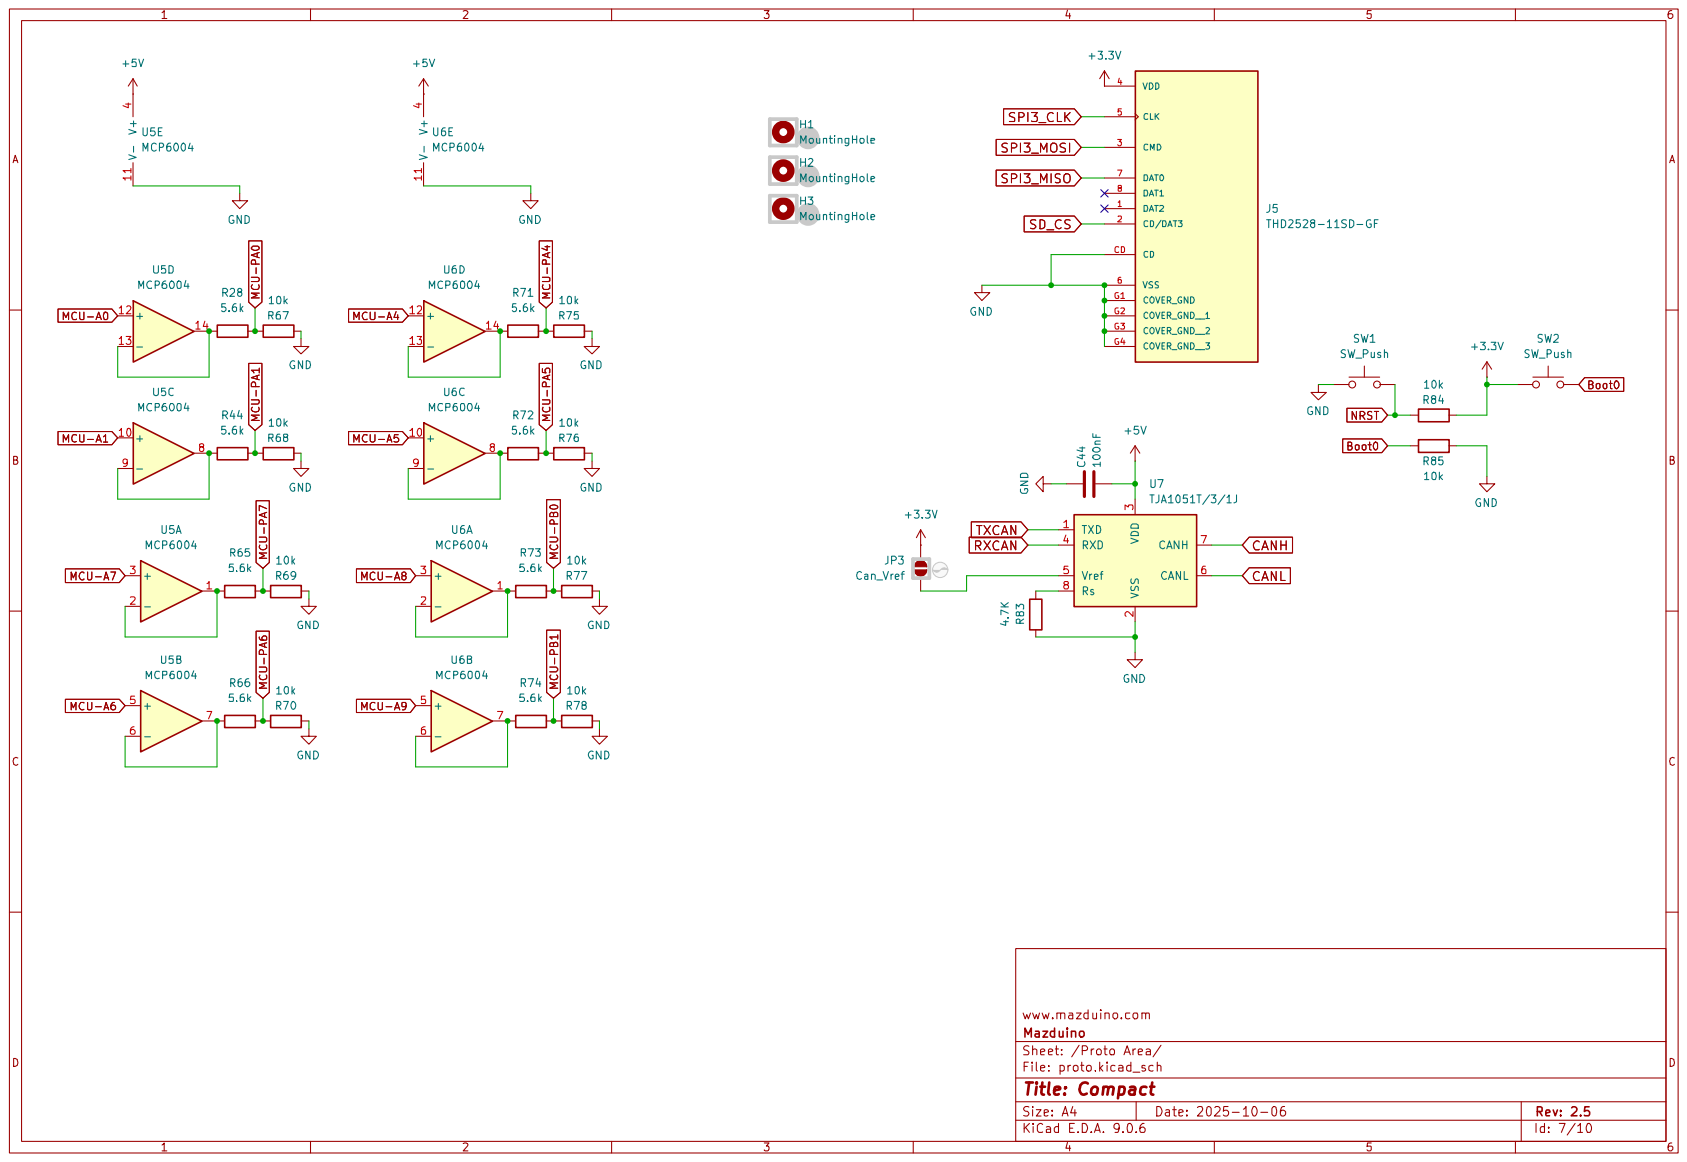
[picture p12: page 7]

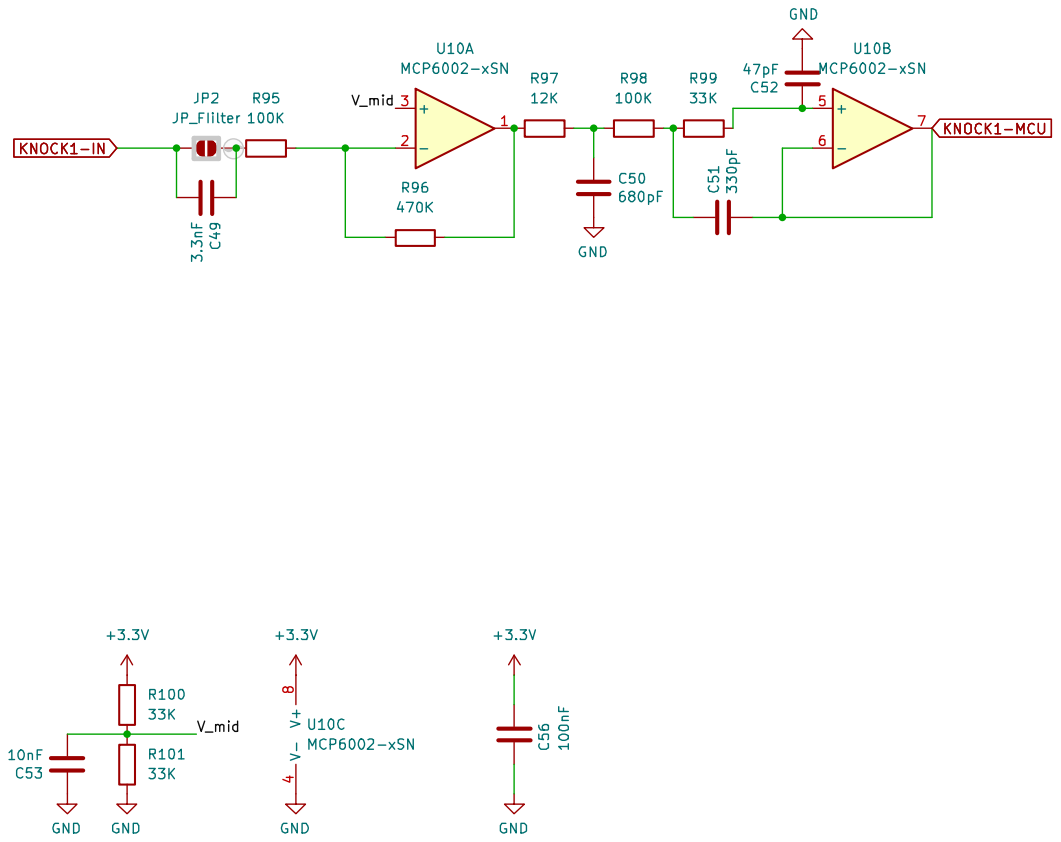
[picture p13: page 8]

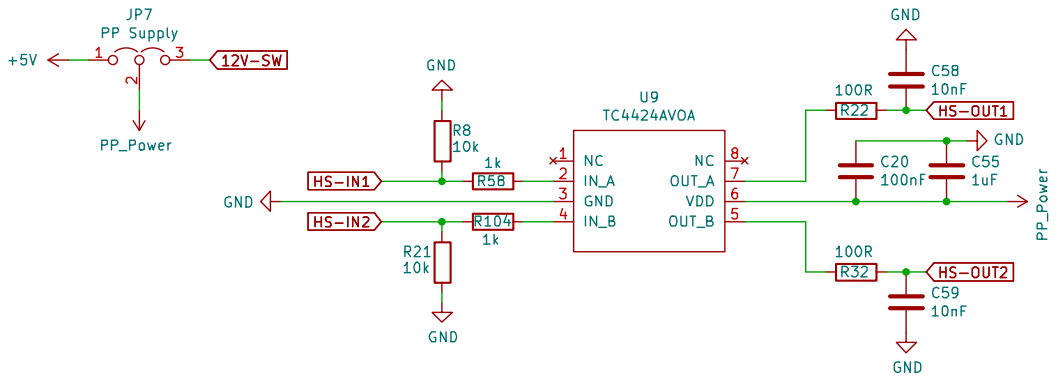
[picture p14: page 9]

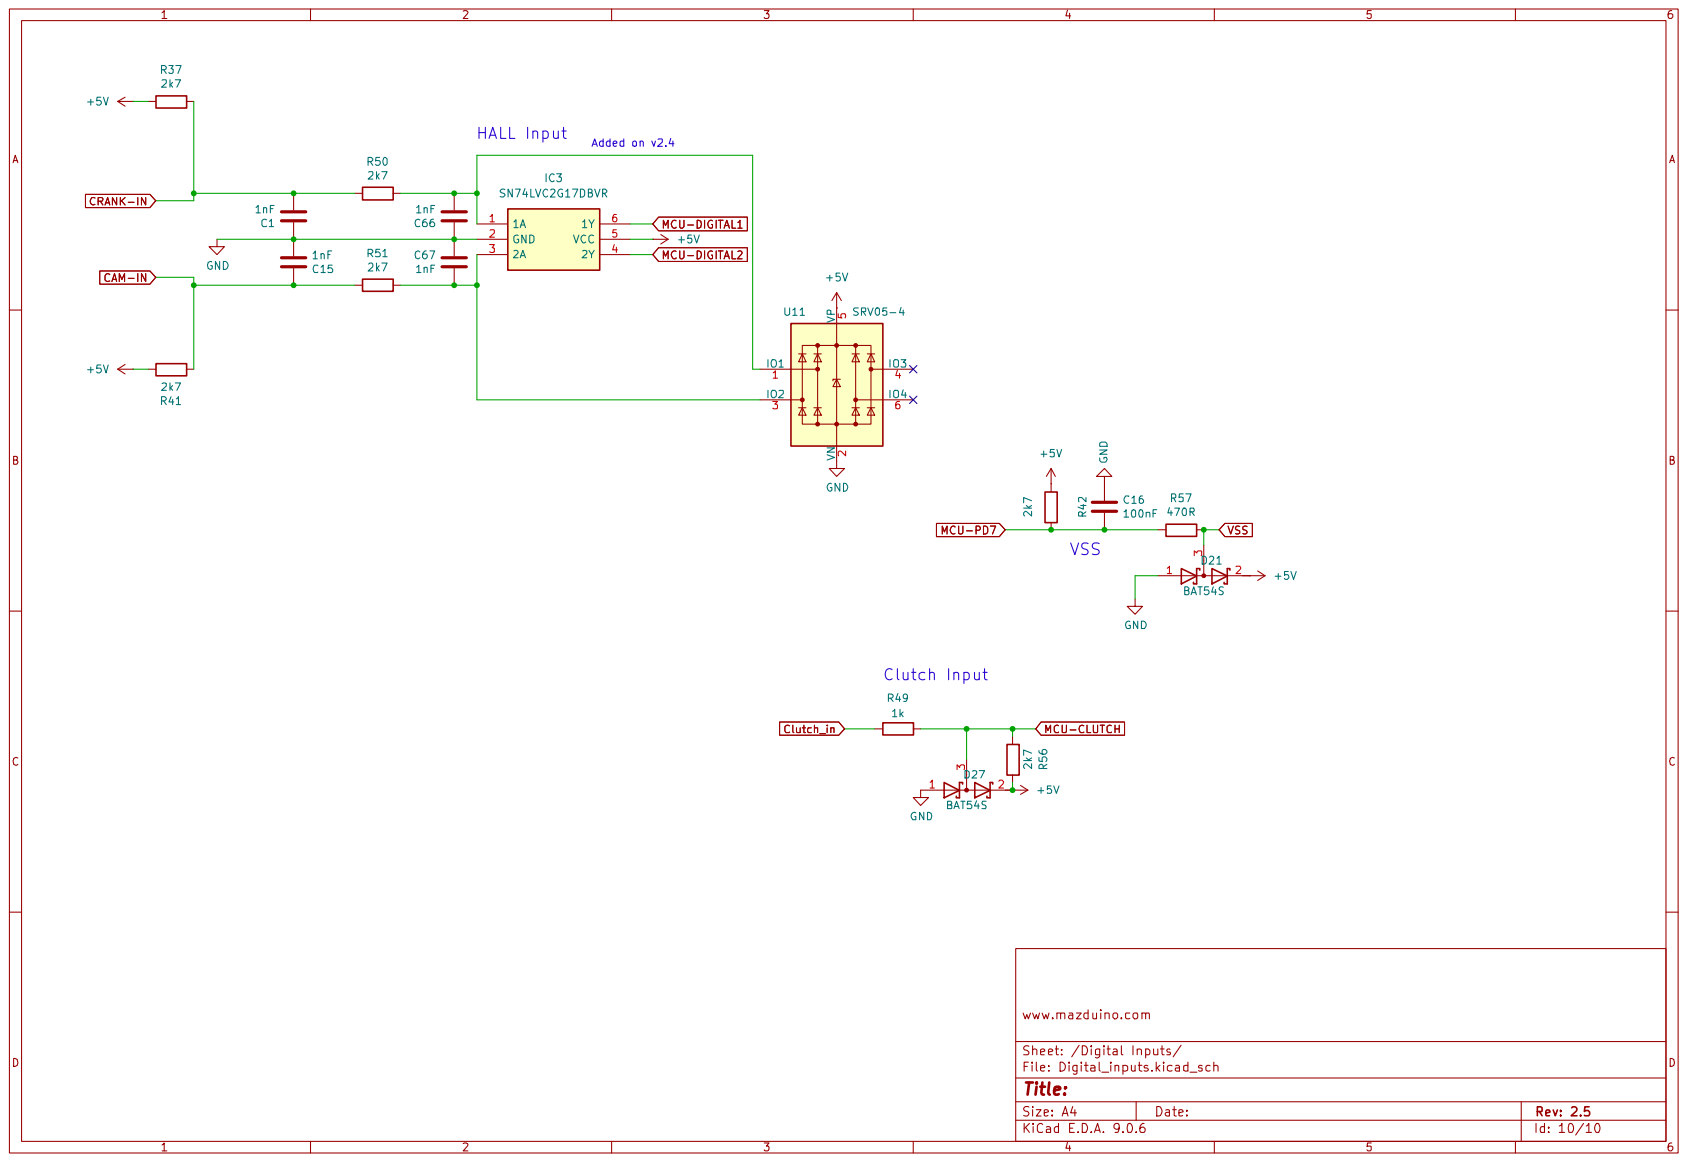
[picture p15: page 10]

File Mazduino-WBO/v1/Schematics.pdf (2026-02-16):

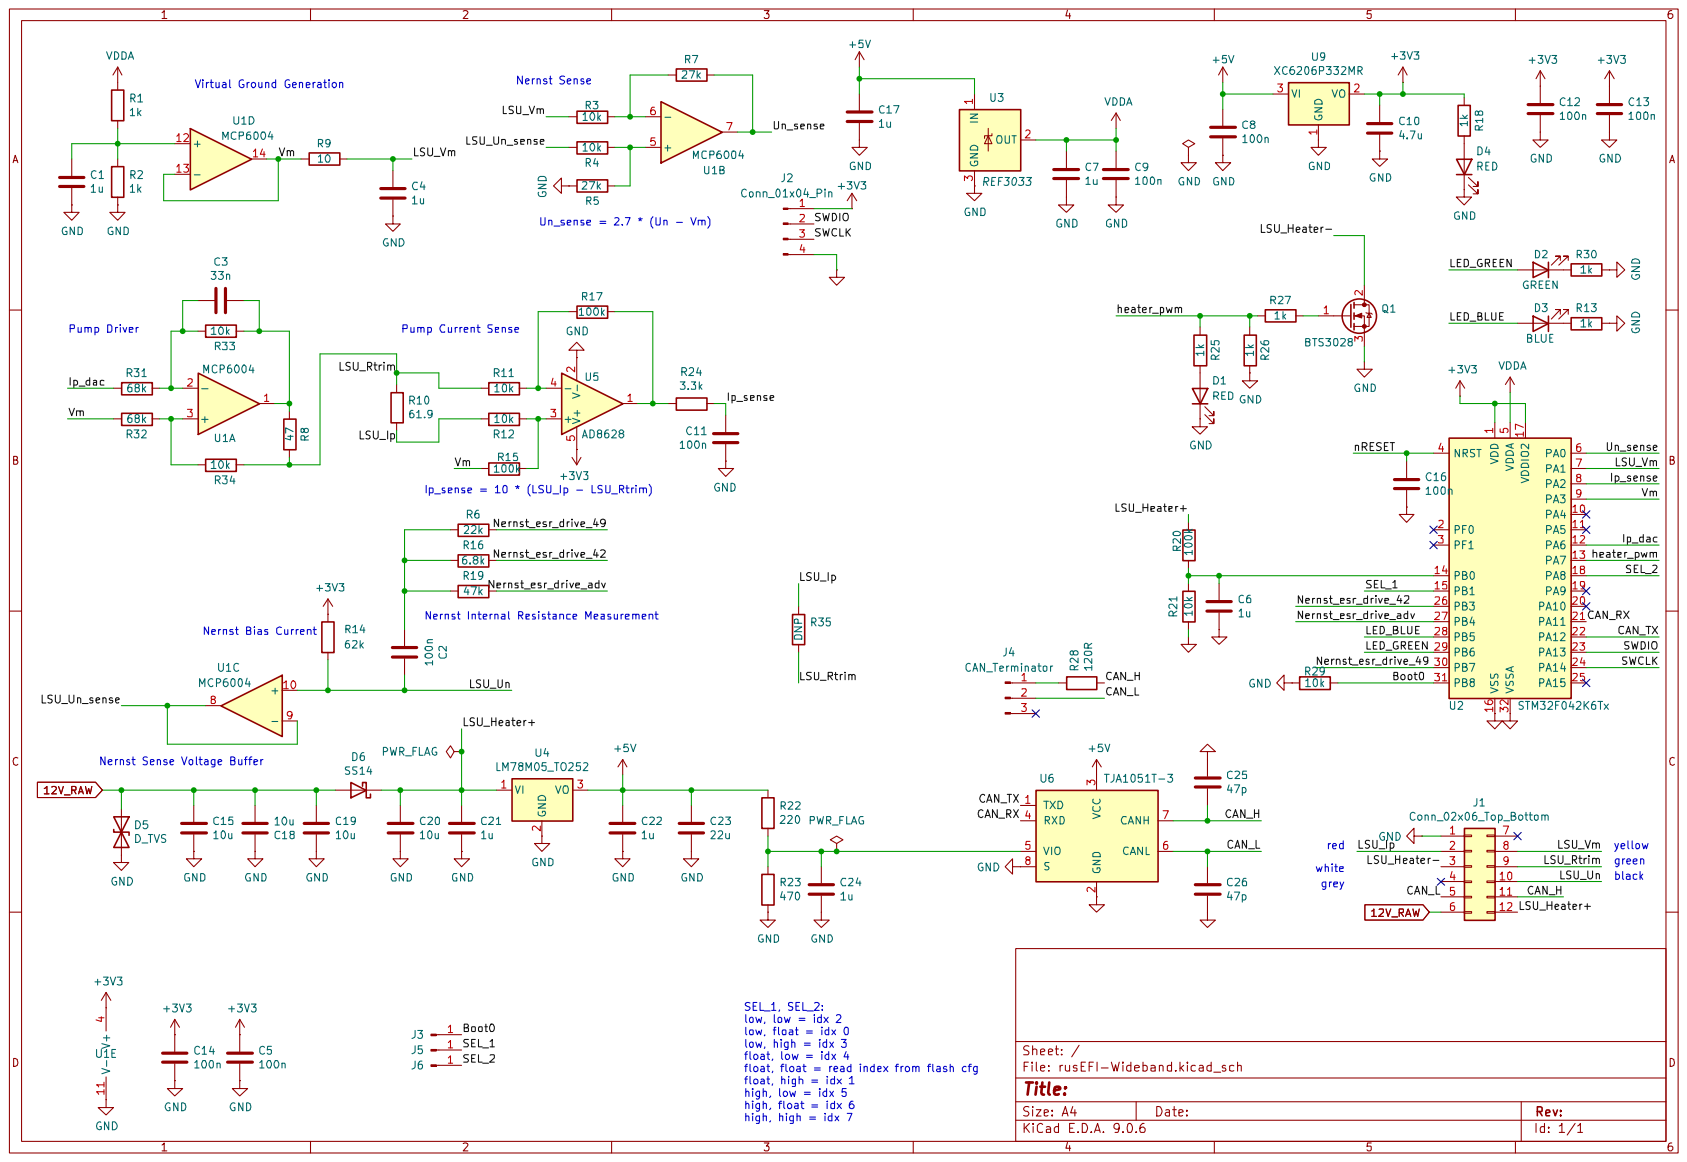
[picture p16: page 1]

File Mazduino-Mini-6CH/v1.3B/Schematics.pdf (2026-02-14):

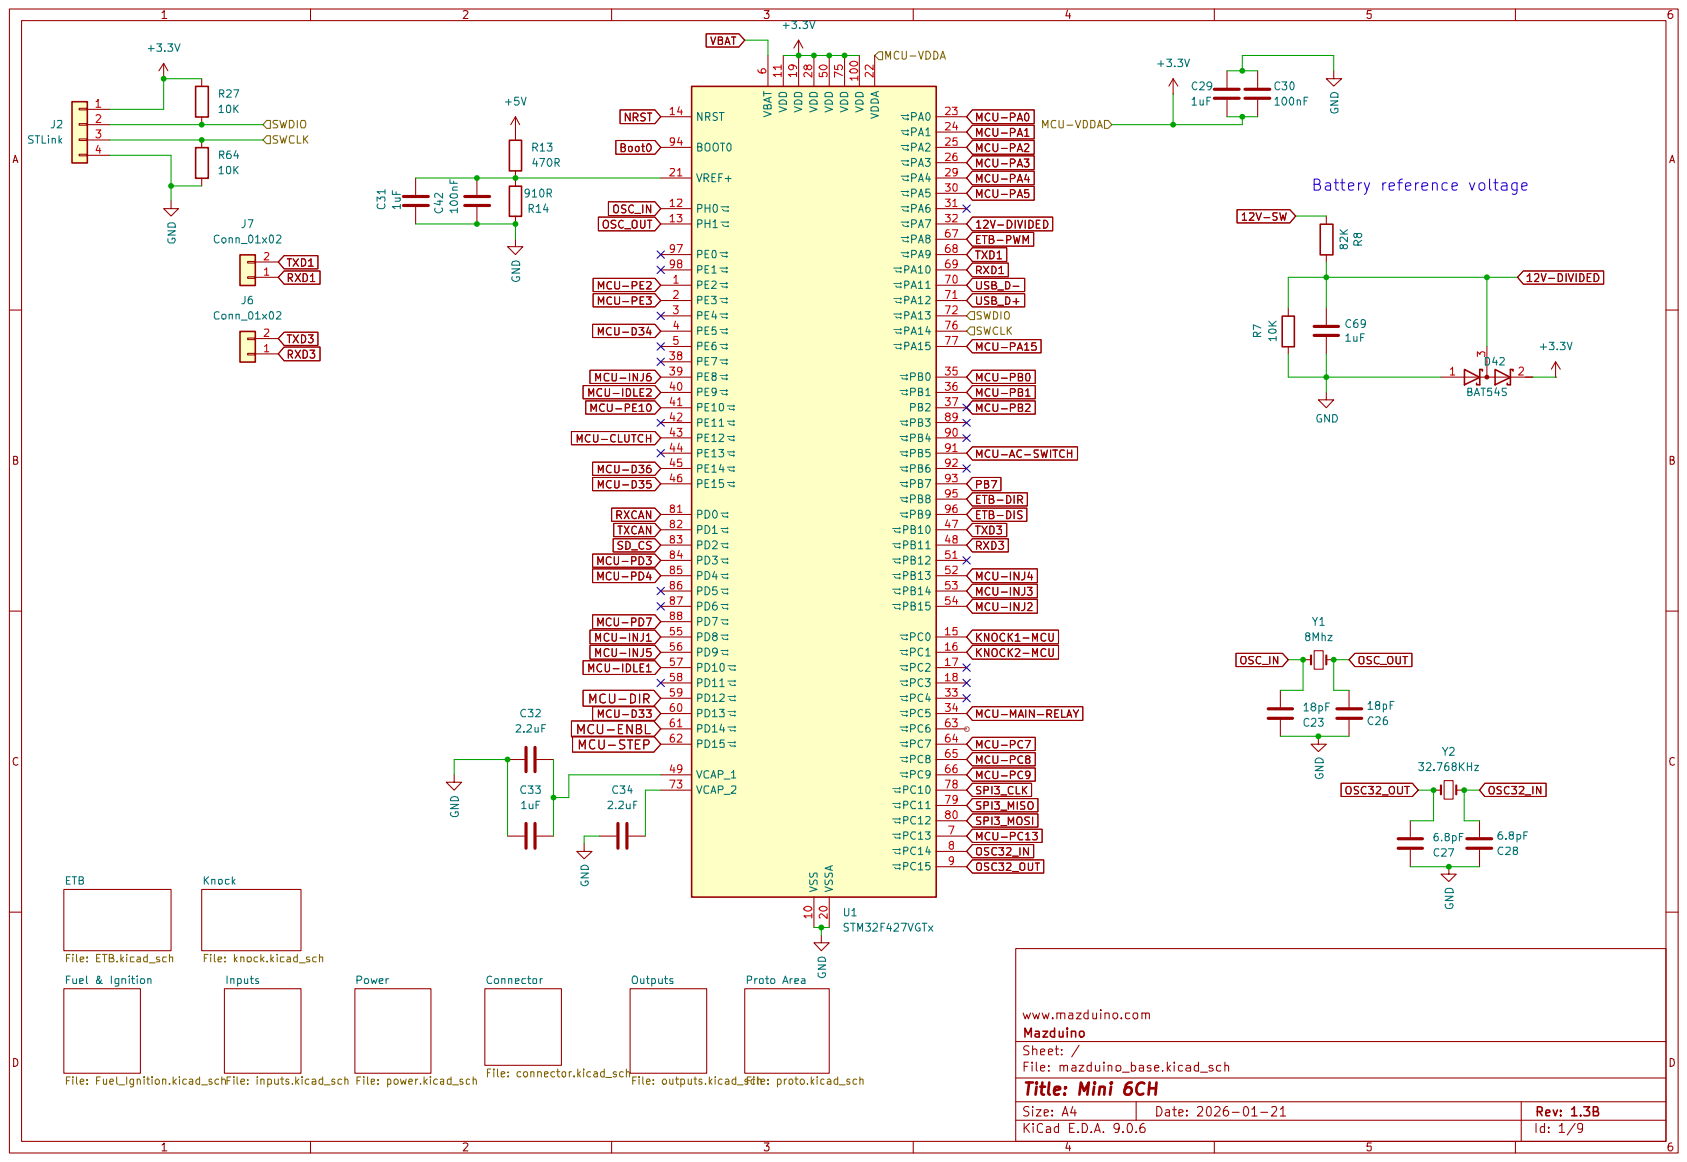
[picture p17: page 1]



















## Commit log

2026-02-03 update firmware and case
    [LITE_BOTTOM.stl.stl, LITE_TOP.stl.stl]
2026-02-16 add wbo
    [bom.csv, designators.csv, positions.csv]
2026-04-13 add compact v2.4 and v2.5
    [bom.csv, designators.csv, positions.csv]
